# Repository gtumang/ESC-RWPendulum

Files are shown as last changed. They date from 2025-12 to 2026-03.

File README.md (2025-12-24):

# ESC-RWPendulum

Este repositório contém o firmware, modelos de simulação e ferramentas de visualização para um sistema de controle de **Pêndulo com Roda de Reação** (Pêndulo Invertido). O projeto foi projetado para estabilizar o pêndulo usando uma roda de reação acionada por um motor DC, controlado por um microcontrolador ESP32.

## Estrutura do Projeto

O repositório está organizado em quatro diretórios principais:

* **`Firmware/`**: Código C++ embarcado para o ESP32, construído usando PlatformIO. Gerencia a leitura de sensores, a execução da malha de controle e a comunicação serial.
* **`Matlab/`**: Scripts MATLAB e modelos Simulink para definição de parâmetros físicos, modelagem matemática e cálculo de ganho de controle (LQR).
* **`Visualization/`**: Scripts Python para telemetria em tempo real, registro de dados e plotagem via Serial.
* **`PCB/`**: Arquivos de projeto da placa de circuito impresso (Hardware), incluindo esquemáticos, layout e arquivos de fabricação.

---

## 1. Firmware (ESP32)

O firmware está localizado no diretório `Firmware` e está configurado como um projeto **PlatformIO**.

### Configuração de Hardware
* **Microcontrolador**: ESP32 (Placa: `fm-devkit`)
* **Atuador**: Motor DC com driver PWM (controlado pelos pinos 25/26).
* **Sensores**: Dois Encoders de Quadratura (Ângulo do Pêndulo e Velocidade da Roda).

**Pinagem (`main.cpp`):**
| Componente | Pino A | Pino B | Notas |
| :--- | :--- | :--- | :--- |
| **Encoder da Roda** | GPIO 17 | GPIO 16 | Mede velocidade/posição da roda de reação |
| **Encoder do Pêndulo** | GPIO 19 | GPIO 18 | Mede o ângulo de inclinação do pêndulo |
| **Driver do Motor** | GPIO 25 | GPIO 26 | Saída PWM (LEDC) |
| **Botão Iniciar/Parar**| GPIO 4 | - | Alterna a malha de controle (ISR) |

### Malha de Controle
* **Algoritmo**: Controle em Espaço de Estados (LQR).
* **Frequência**: 50 Hz (`Ts = 0.02s`).
* **Estados**:
    1.  $x_1$: Ângulo do Pêndulo (rad)
    2.  $x_2$: Ângulo da Roda (rad)
    3.  $x_3$: Velocidade do Pêndulo (rad/s)
    4.  $x_4$: Velocidade da Roda (rad/s)
* **Comunicação**: Envia dados de estado e esforço de controle via Serial (Formato binário).

---
## 2. MATLAB & Simulação

O diretório `Matlab` contém a fundação matemática do projeto.

* **`Scripts/SalvaParams.m`**: Define as constantes físicas do sistema (massas, comprimentos, inércia, constantes do motor) e as salva em `Parametros/parametros_planta.mat`.
    * *Parâmetros incluem:* $M_h$ (Massa da haste), $M_r$ (Massa do rotor), $L$ (Comprimento), $J_h$ (Inércia), etc.
* **`PenduloRotativoSim.slx`**: Modelo Simulink para simular a dinâmica do sistema e a resposta do controlador.
* **`Funcoes/`**: Contém funções geradas automaticamente (`function_G_Rot`, `function_M_Rot`, etc.) para a simulação não linear do sistema.
* **`Parametros/`**: Armazena arquivos `.mat` com a matriz de ganho de controle `K` calculada.

**Como usar:**
1.  Edite os parâmetros físicos em `SalvaParams.m` e execute-o.
2.  Execute o script de análise principal (ex: `main.mlx`) para calcular a matriz de ganho LQR $K$.
3.  Atualize a struct `K` em `Firmware/src/main.cpp` com os valores calculados.

---

## 3. Visualização (Python)

O diretório `Visualization` fornece ferramentas para visualizar dados do sistema em tempo real.

### Requisitos
* Python 3.x
* Bibliotecas: `pyserial`, `matplotlib`

### Scripts
* **`ler_pendulo.py`**: Um utilitário simples para ler dados brutos da porta serial e imprimir os valores decodificados em ponto flutuante no console.
* **`plot_pendulo.py`**: Uma ferramenta de plotagem em tempo real.
    * **Uso**: `python plot_pendulo.py --port COM3`
    * **Recursos**:
        * Plota múltiplas variáveis dinamicamente.
        * Suporta um modo de simulação para testar a interface sem hardware: `python plot_pendulo.py --sim`.
        * Visualiza Ângulo, Velocidade e Esforço de Controle ($u$).

---

## 4. Hardware e PCB (KiCad)

O diretório **`PCB`** contém todo o projeto eletrônico necessário para fabricar a placa de controle customizada do pêndulo, desenvolvido no software **KiCad**.

### Estrutura dos Arquivos
* **`RWPendulum/`**: Contém os arquivos fonte do projeto KiCad, incluindo o esquemático (`.kicad_sch`) e o layout da PCB (`.kicad_pcb`). O design integra o módulo ESP32 DevKit V1 e o driver de motor.
* **`OutputFiles/`**: Arquivos gerados para fabricação da placa:
    * **`Gerber/`**: Arquivos Gerber para as camadas de cobre, máscara de solda e corte.
    * **`Drill/`**: Arquivos de furação (PTH e NPTH).
* **`3D/`**: Modelos 3D (.step) da placa completa e componentes específicos (ex: Driver MD36A) para visualização mecânica e validação de encaixe.

---

## Licença
*Nenhuma licença especificada nos arquivos do repositório*.

## Autor
**Gabriel Brunoro Motta Tumang**

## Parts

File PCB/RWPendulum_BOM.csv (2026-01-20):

Id | Designator | Footprint | Quantity | Designation | Supplier and ref
1 | SW2 | SW_PUSH_6mm_H4.3mm | 1 | SW_Push
2 | C1,C2,C4,C3 | C_Disc_D5.0mm_W2.5mm_P5.00mm | 4 | 100nF
3 | IC1 | TO255P460X1020X2008-3P | 1 | L7805CV
4 | J1,J4 | TerminalBlock_MaiXu_MX126-5.0-02P_1x02_P5.00mm | 2 | Screw_Terminal_01x02
5 | C5 | CP_Radial_D8.0mm_P3.50mm | 1 | 470uF
6 | F1 | Fuseholder_Cylinder-5x20mm_Schurter_0031_8201_Horizontal_Open | 1 | Fuse
7 | U2 | ESP32-C3-DevKitM-1 | 1 | ESP32-DEVKIT-V1
8 | D1 | LED_D3.0mm | 1 | LED
9 | J3 | Molex_KK-396_A-41792-0004_1x04_P3.96mm_Horizontal | 1 | Conn_01x04_Pin
10 | J2 | Molex_KK-396_A-41792-0006_1x06_P3.96mm_Horizontal | 1 | Conn_01x06_Pin
11 | A1 | MD36A Motor Driver Header | 1 | ~
12 | R2 | R_Axial_DIN0207_L6.3mm_D2.5mm_P10.16mm_Horizontal | 1 | 600
13 | SW1 | TerminalBlock_MaiXu_MX126-5.0-02P_1x02_P5.00mm | 1 | SW_SPST

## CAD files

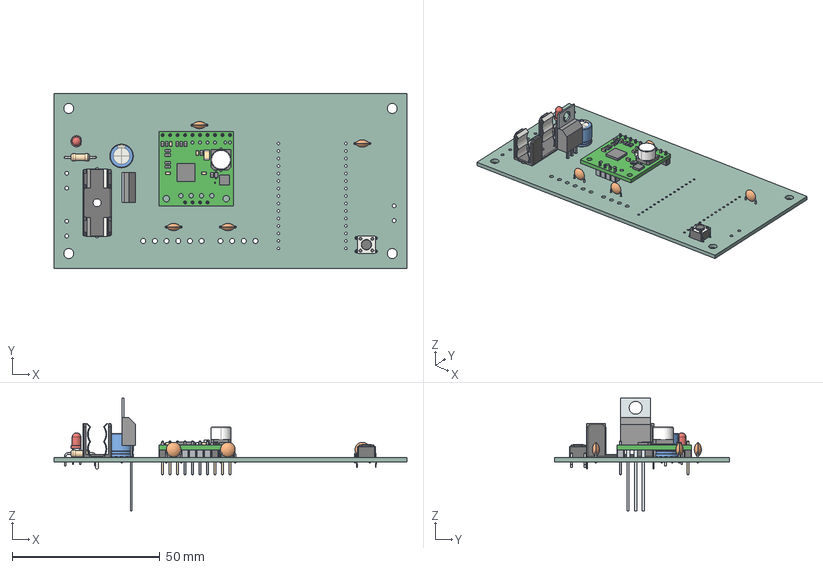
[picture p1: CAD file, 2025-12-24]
PCB/3D/RWPendulum.step
119.6 x 59.2 x 38.3 mm
SW_PUSH_6mm_H4.3mm
C_Disc_D5.0mm_W2.5mm_P5.00mm x 4
Tab
PinsArray
CP_Radial_D8.0mm_P3.50mm
Fuseholder_Cylinder-5x20mm_Schurter_0031_8201_Horizontal_Open
LED_D3.0mm
Barra10Pinos
tb9051ftg_single_brushed_dc_motor_driver_carrier
Slice.1
R_Axial_DIN0207_L6.3mm_D2.5mm_P10.16mm_Horizontal
RWPendulum_PCB

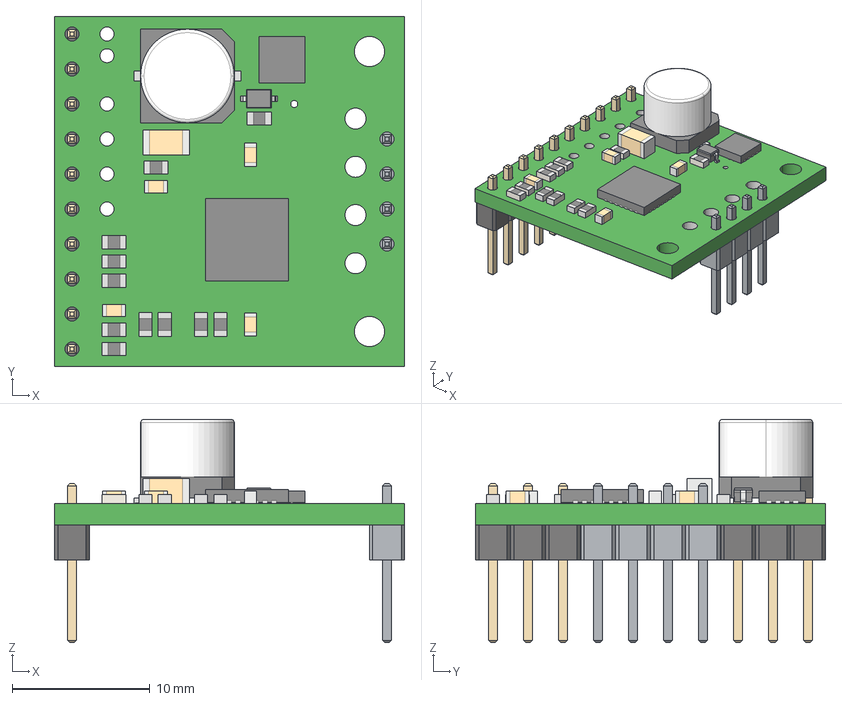
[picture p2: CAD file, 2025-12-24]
PCB/3D/MD36A_MotorDriver_Header.step
25.4 x 25.4 x 16.2 mm
Barra10Pinos
tb9051ftg_single_brushed_dc_motor_driver_carrier
Slice.1

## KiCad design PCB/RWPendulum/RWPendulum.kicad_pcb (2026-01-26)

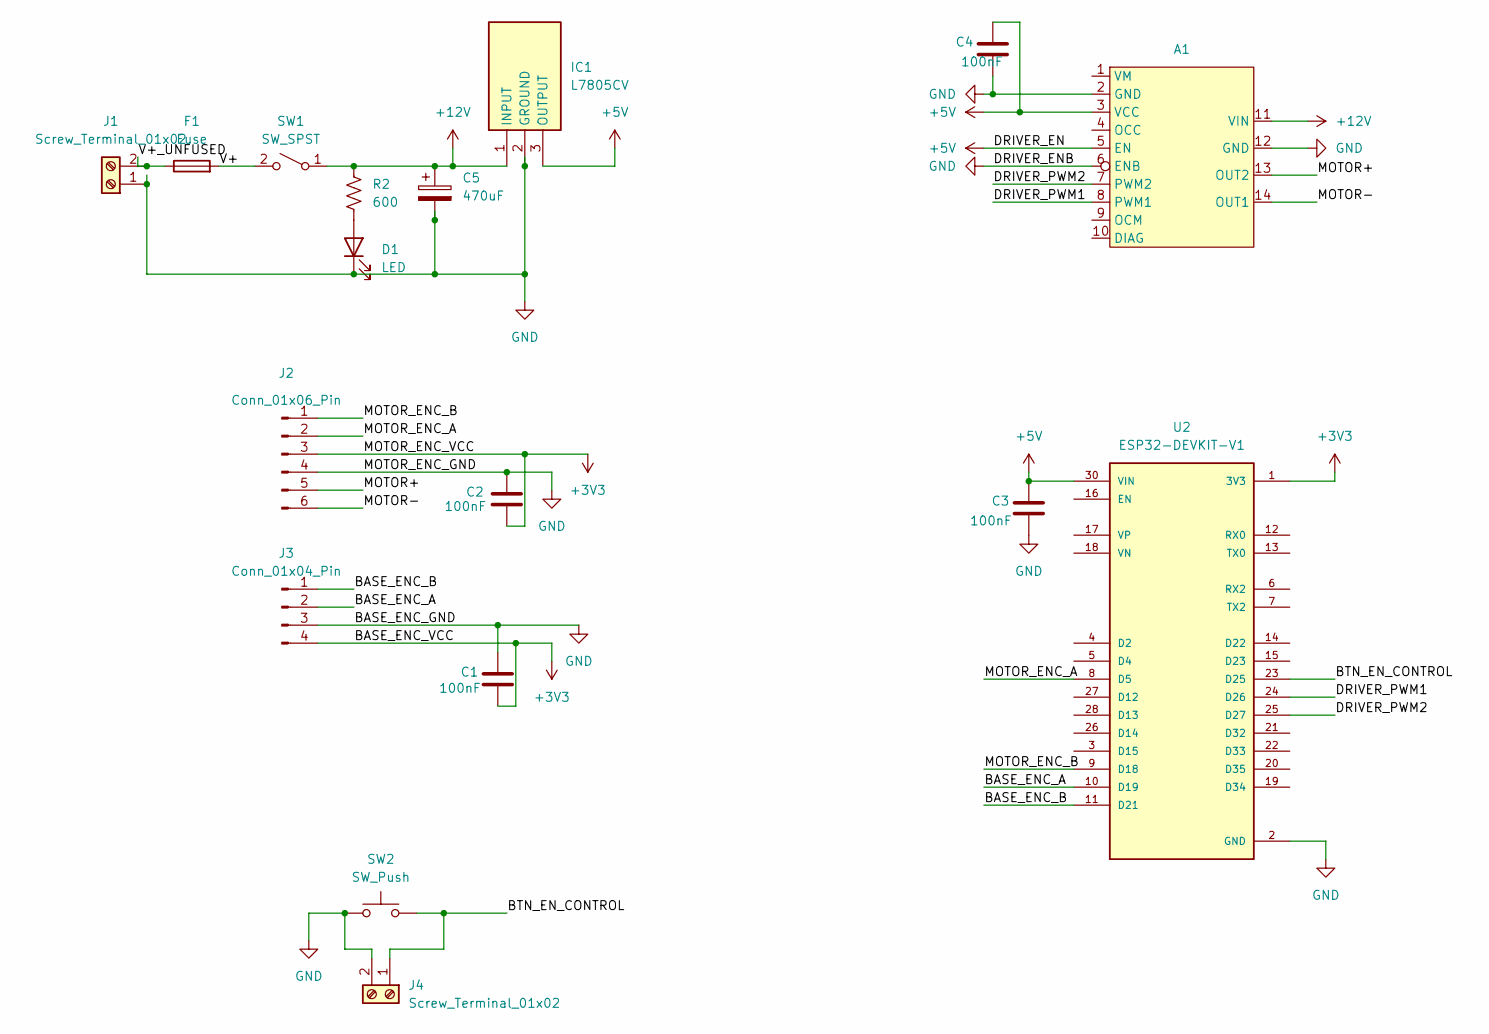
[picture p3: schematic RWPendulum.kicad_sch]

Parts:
A1: MD36A Motor Driver Header
C1, C2, C3, C4: 100nF; C_Disc_D5.0mm_W2.5mm_P5.00mm
C5: 470uF; CP_Radial_D8.0mm_P3.50mm
D1: LED; LED_D3.0mm
F1: Fuse; Fuseholder_Cylinder-5x20mm_Schurter_0031_8201_Horizontal_Op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
IC1: L7805CV; TO255P460X1020X2008-3P; Manufacturer_Part_Number L7805CV; Mouser Part Number 511-L7805CV
J1, J4: Screw_Terminal_01x02; TerminalBlock_MaiXu_MX126-5.0-02P_1x02_P5.00mm
J2: Conn_01x06_Pin; Molex_KK-396_A-41792-0006_1x06_P3.96mm_Horizontal
J3: Conn_01x04_Pin; Molex_KK-396_A-41792-0004_1x04_P3.96mm_Horizontal
R2: 600; R_Axial_DIN0207_L6.3mm_D2.5mm_P10.16mm_Horizontal
SW1: SW_SPST; TerminalBlock_MaiXu_MX126-5.0-02P_1x02_P5.00mm
SW2: SW_Push; SW_PUSH_6mm_H4.3mm
U2: ESP32-DEVKIT-V1; ESP32-C3-DevKitM-1; PARTREV N/A

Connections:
+3V3: C1.2, C2.2, J2.3, J3.4, U2.1 (3V3)
+5V: A1.3 (VCC), A1.5 (EN), C3.1, C4.1, IC1.3 (OUTPUT), U2.30 (VIN)
+12V: A1.11 (VIN), C5.1, IC1.1 (INPUT), R2.2, SW1.1 (A)
/BASE_ENC_A: J3.2, U2.10 (D19)
/BASE_ENC_B: J3.1, U2.11 (D21)
/BTN_EN_CONTROL: J4.1, SW2.2, U2.23 (D25)
/DRIVER_PWM1: A1.8 (PWM1), U2.24 (D26)
/DRIVER_PWM2: A1.7 (PWM2), U2.25 (D27)
/MOTOR+: A1.13 (OUT2), J2.5
/MOTOR-: A1.14 (OUT1), J2.6
/MOTOR_ENC_A: J2.2, U2.8 (D5)
/MOTOR_ENC_B: J2.1, U2.9 (D18)
/V+: F1.2, SW1.2 (B)
/V+_UNFUSED: F1.1, J1.2
GND: A1.2 (GND), A1.6 (ENB), A1.12 (GND), C1.1, C2.1, C3.2, C4.2, C5.2, D1.1 (K), IC1.2 (GROUND), J1.1, J2.4, J3.3, J4.2, SW2.1, U2.2 (GND), U2.29 (GND)
unnamed: D1.2 (A), R2.1

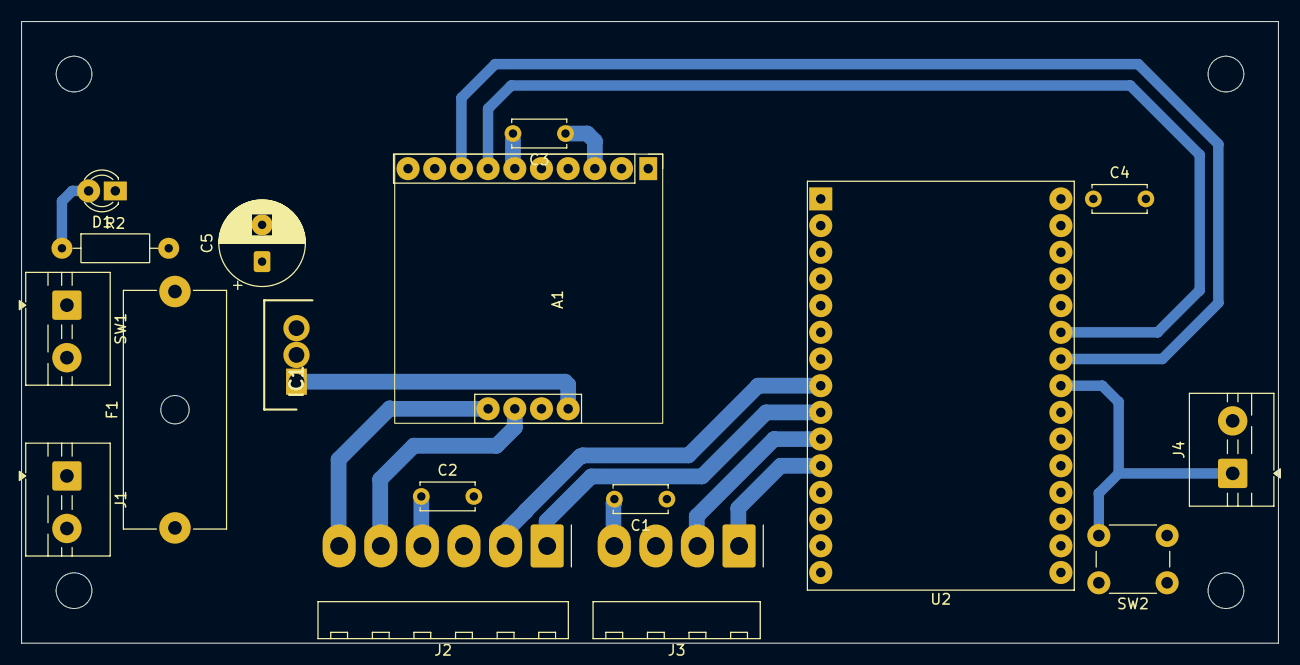
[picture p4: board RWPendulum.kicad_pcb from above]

Board: 2 copper layers, 119.6 x 59.2 mm, 17 parts (0 on the bottom side), 16 nets.

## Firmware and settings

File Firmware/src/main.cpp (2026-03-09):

#include <Arduino.h>
#include <ESP32Encoder.h>
#include "defines.h"



// Definições para adquirir informações
// Condicoes iniciais
#if ACQSIGNAL==true
#define acq_time 10.0 //s
#define acq_arr_size acq_time/Ts
const int arr_size = (int) acq_arr_size;
estados_t state_arr[arr_size];
bool acq_done = false;
int i = 0;
#endif

// Variaveis Globais Auxiliares p/ Lógica
estados_t estados{
  .x1 = 0.0f,
  .x2 = 0.0f,
  .x3 = 0.0f,
  .x4 = 0.0f
};
estados_t estados_ant{
  .x1 = 0.0f,
  .x2 = 0.0f,
  .x3 = 0.0f,
  .x4 = 0.0f
};
estados_t estados_ant_unf{
  .x1 = 0.0f,
  .x2 = 0.0f,
  .x3 = 0.0f,
  .x4 = 0.0f
};
// Ganho controlador
static const estados_t K{
  .x1 = LQR_K1,
  .x2 = LQR_K2,
  .x3 = LQR_K3,
  .x4 = LQR_K4
};
volatile bool aux = false;
bool enable_cont = false;
double u_hist=0;


//// Objetos globais
// Encoder
ESP32Encoder enc_roda;
ESP32Encoder enc_pend;
// Timer
hw_timer_t *timer = NULL;
// RTOS
TaskHandle_t handleControle;
TaskHandle_t handleComunicacao;
SemaphoreHandle_t handleMutex = NULL;

// Configuração PWM
const int pwmChannelA = 0;
const int pwmChannelB = 1;
const int pwmResolution = 8;
const int pwmFrequency = 10000;

void IRAM_ATTR onTimer() {
  aux = true;
}

// Declarações de Funções
void drive(float u);
void montaMensagem(u_char* msg, estados_t estados);
double ajusta_angulo(double angulo);
double controle(estados_t x, estados_t k);
static const double backwards_uf(double q, double q_ant, double ts);
static const double backwards_filtered(double q, double q_ant, double qp_ant, double qp_ant_uf, double a, double b, double ts);
static const double sign(double x);

// Definição das Funções-Tarefas
void taskControle(void* pvParameters);
void taskComunicacao(void* pvParameters);

// ISRs
void enable_cont_ISR(){
  enable_cont = !enable_cont;
}

void setup() {
  Serial.begin(9600);

  // ConfiguraÇão botoes
  pinMode(BOTAO_CONT, INPUT_PULLUP);
  // pinMode(BOTAO_SU, INPUT_PULLDOWN);
  attachInterrupt(digitalPinToInterrupt(BOTAO_CONT), enable_cont_ISR, RISING);

  // Configuração dos encoders
  pinMode(ENC_RODA_A, INPUT);
  pinMode(ENC_RODA_B, INPUT);
  ESP32Encoder::useInternalWeakPullResistors = puType::up;
  enc_roda.attachFullQuad(ENC_RODA_A, ENC_RODA_B);
  enc_pend.attachFullQuad(ENC_PEND_A, ENC_PEND_B);
  enc_roda.clearCount();
  enc_pend.clearCount();

  // Configuração do motor
  ledcSetup(pwmChannelA, pwmFrequency, pwmResolution);
  ledcSetup(pwmChannelB, pwmFrequency, pwmResolution);
  ledcAttachPin(IN_A, pwmChannelA);
  ledcAttachPin(IN_B, pwmChannelB);

  // LED onboard
  pinMode(ONBOARD_LED, OUTPUT);
  digitalWrite(ONBOARD_LED, HIGH);

  // Configuração do timer
  timer = timerBegin(0, 80, true); // Divisor de 80 (1MHz)
  timerAttachInterrupt(timer, &onTimer, true);
  timerAlarmWrite(timer, Ts * 1000000, true);
  timerAlarmEnable(timer);
  
  // Pega ângulo inicial
  Serial.println("");
  Serial.println("-----------------------");
  Serial.println("-------Iniciando!------");
  Serial.println("-----------------------");

  // Configura mutex
  handleMutex = xSemaphoreCreateMutex();

  delay(1000); // Espera inicial de 5 segundos

  // Configura taks
  xTaskCreatePinnedToCore(
    taskControle,
    "TaskControle",
    1000,
    NULL,
    1,
    &handleControle,
    1
  );

  xTaskCreatePinnedToCore(
    taskComunicacao,
    "TaskComunicacao",
    1000,
    NULL,
    1,
    &handleComunicacao,
    0
  );
}

void taskControle(void* pvParameteres){
  for(;;){
    if(aux) {
      aux = false;
      if(xSemaphoreTake(handleMutex, portMAX_DELAY)) {


        estados.x1 = enc_pend.getCount() * en2rad_pend;
        estados.x2 = enc_roda.getCount() * en2rad_roda;
        estados.x3 = backwards_uf(estados.x1, estados_ant.x1, Ts);
        estados.x4 = backwards_uf(estados.x2, estados_ant.x2, Ts);

        estados_ant = estados;

        estados.x1 = ajusta_angulo(estados.x1);

        double u = controle(estados, K);

        if(!enable_cont) u=0.0f;
        drive(u);

        u_hist = u;
        xSemaphoreGive(handleMutex);
      }
    }
  }
}

void taskComunicacao(void* pvParameters){
  estados_t X_com = {
    .x1 = 0.0,
    .x2 = 0.0,
    .x3 = 0.0,
    .x4 = 0.0,
  };
  u_char* msg = (u_char*) malloc(TAMANHO_FRAME);
  for(;;){
    
    if(xSemaphoreTake(handleMutex, 200 * portTICK_PERIOD_MS)){
      X_com = estados;
      xSemaphoreGive(handleMutex);
      montaMensagem(msg, X_com);
      Serial.write(msg, TAMANHO_FRAME);
    }
    delay(100);
  }
  free(msg);
};

void loop() {}

void drive(float u) {
  int direction = 0;
  if (u > 0) direction = 1;
  if (u < 0) direction = 2;

  u = fabs(u);
  u = constrain(u, 0.0f, 1.0f);
  //ledcWrite(pwmChannel, (uint32_t)(u * 255));

  switch(direction) {
    case 0:
      ledcWrite(pwmChannelA, (uint32_t)(0 * 255));
      ledcWrite(pwmChannelB, (uint32_t)(0 * 255));
      break;
    case 1:
    
      ledcWrite(pwmChannelA, (uint32_t)(u * 255));
      ledcWrite(pwmChannelB, (uint32_t)(0 * 255));
      break;
    case 2:
      ledcWrite(pwmChannelA, (uint32_t)(0 * 255));
      ledcWrite(pwmChannelB, (uint32_t)(u * 255));
      break;
  }
}

static const double backwards_uf(double q, double q_ant, double ts){
  return 1.0f/Ts*(q - q_ant);
}
static const double backwards_filtered(double q, double q_ant, double qp_ant, double qp_ant_uf, double a, double b, double ts){
  return a*(backwards_uf(q, q_ant, ts) + qp_ant_uf) - b*qp_ant;
}

static const double sign(double x){
  return x!=0 ? x/abs(x) : 0;
}

double ajusta_angulo(double angulo){
  if(abs(angulo) > 2*pi){
    angulo = fmod(angulo, 2*pi);
  }
  double angulo_pra_cima = angulo - sign(angulo)*pi;
  return angulo_pra_cima;
}

double controle(estados_t x, estados_t k){
  return -k.x1 * x.x1 -k.x2 * x.x2 -k.x3 * x.x3 -k.x4 * x.x4;
}

void montaMensagem(u_char* msg, estados_t estados){
  msg[0] = 0xFF;
  memcpy(msg + 1 + 0*DOUBLE_SIZE, &estados.x1, DOUBLE_SIZE);
  memcpy(msg + 1 + 1*DOUBLE_SIZE, &estados.x2, DOUBLE_SIZE);
  memcpy(msg + 1 + 2*DOUBLE_SIZE, &estados.x3, DOUBLE_SIZE);
  memcpy(msg + 1 + 3*DOUBLE_SIZE, &estados.x4, DOUBLE_SIZE);
  memcpy(msg + 1 + 4*DOUBLE_SIZE, &u_hist, DOUBLE_SIZE);
  msg[1 + TAMANHO_PAYLOAD] = 0x00;
}

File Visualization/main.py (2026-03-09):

#!/usr/bin/env python3
"""
plot_multi_dynamic.py

Leitura de frames seriais: 0xFF (5 doubles little-endian) 0x00
Cria múltiplas figuras matplotlib dinamicamente a partir do mesmo stream.
Cada figura pode plotar qualquer combinação das variáveis d1..d5.
"""

import argparse
import struct
import threading
import time
from collections import deque
from typing import List, Tuple

import matplotlib.pyplot as plt
import matplotlib.animation as animation

# --- opcional: pyserial para leitura real ---
try:
    import serial
except Exception:
    serial = None

# --- Configurações padrão ---
SERIAL_PORT = "COM4"    # ex: "COM3" no Windows
BAUDRATE = 9600
TIMEOUT = 0.5

START_BYTE = 0xFF
END_BYTE = 0x00
DOUBLES_COUNT = 5
DOUBLE_SIZE = 8
PAYLOAD_SIZE = DOUBLES_COUNT * DOUBLE_SIZE  # 40 bytes

BUFFER_SECONDS = 30
UPDATE_INTERVAL_MS = 100
MAX_POINTS = int(BUFFER_SECONDS * 1000 / UPDATE_INTERVAL_MS)

# --- leitor serial em background (preenche deque) ---
def read_frame_from_serial(ser) -> Tuple[float, ...] or None:
    """Lê um frame e retorna tuple (d1..d5) ou None se timeout/erro."""
    # procurar start
    while True:
        b = ser.read(1)
        if not b:
            return None
        if b[0] == START_BYTE:
            break

    payload = bytearray()
    remaining = PAYLOAD_SIZE
    while remaining > 0:
        chunk = ser.read(remaining)
        if not chunk:
            return None
        payload.extend(chunk)
        remaining = PAYLOAD_SIZE - len(payload)

    end = ser.read(1)
    if not end or end[0] != END_BYTE:
        return None

    try:
        return struct.unpack("<5d", payload)
    except struct.error:
        return None


def serial_reader_thread(data_deque: deque, lock: threading.Lock, stop_event: threading.Event,
                         port: str, baud: int, timeout: float, simulate: bool):
    """
    Popula data_deque com tuplas (timestamp, d1, d2, d3, d4, d5).
    Usar lock ao acessar data_deque para thread-safety.
    """
    if simulate:
        print("SIMULANDO dados (modo --sim).")
        import math
        t0 = time.time()
        while not stop_event.is_set():
            t = time.time()
            d1 = 2.0 * math.sin(2 * math.pi * 0.2 * (t - t0)) + 0.1 * math.sin(t * 3.3)
            d2 = 0.5 * math.sin(2 * math.pi * 0.5 * (t - t0))
            d3 = 0.2 * math.cos(2 * math.pi * 0.8 * (t - t0))
            d4 = 0.0
            d5 = 1.5 * math.cos(2 * math.pi * 0.1 * (t - t0)) + 0.05 * math.sin(t * 1.7)
            with lock:
                data_deque.append((t, d1, d2, d3, d4, d5))
                while len(data_deque) > MAX_POINTS:
                    data_deque.popleft()
            time.sleep(UPDATE_INTERVAL_MS / 1000.0)
        return

    # leitura real
    if serial is None:
        print("pyserial não disponível. Instale 'pyserial' ou use --sim.")
        return

    try:
        ser = serial.Serial(port, baud, timeout=timeout)
    except Exception as e:
        print("Erro abrindo serial:", e)
        return

    print(f"Conectado em {port} @ {baud}")
    try:
        while not stop_event.is_set():
            frame = read_frame_from_serial(ser)
            if frame is None:
                continue
            t = time.time()
            with lock:
                data_deque.append((t, *frame))
                while len(data_deque) > MAX_POINTS:
                    data_deque.popleft()
    finally:
        ser.close()


# --- função reutilizável que cria uma figura/animation ---
def create_figure(
    data_deque: deque,
    lock: threading.Lock,
    var_indices: List[int],
    *,
    separate_y: bool = False,
    buffer_seconds: float = BUFFER_SECONDS,
    update_interval_ms: int = UPDATE_INTERVAL_MS,
    fig_title: str = None,
) -> Tuple[plt.Figure, animation.FuncAnimation]:
    """
    Cria uma figura que plota as variáveis em var_indices (1-based: 1..5).
    - var_indices: lista de índices (ex: [1,5] para d1 e d5).
    - separate_y: se True cria subplots empilhados, um por variável (eixos Y independentes),
                  se False plota todas no mesmo eixo (mesmo Y).
    Retorna (fig, anim) — mantenha references no caller para evitar GC.
    """
    # valida índices
    for idx in var_indices:
        if idx < 1 or idx > DOUBLES_COUNT:
            raise ValueError("var_indices deve conter valores entre 1 e 5 (inclusive)")

    n_vars = len(var_indices)
    fig = None
    axes = []
    lines = []
    last_texts = []

    if separate_y:
        fig, axes = plt.subplots(n_vars, 1, sharex=True, figsize=(8, 3 * n_vars))
        # quando n_vars == 1, axes pode não ser uma lista
        if n_vars == 1:
            axes = [axes]
        for i, ax in enumerate(axes):
            ax.grid(True)
            ax.set_ylabel(f"d{var_indices[i]}")
            ln, = ax.plot([], [], lw=1, label=f"d{var_indices[i]}")
            ax.legend(loc="upper right")
            lines.append(ln)
            last_texts.append(ax.text(0.02, 0.9, "", transform=ax.transAxes, va="top"))
        axes[-1].set_xlabel("Tempo (s, relativo)")
        if fig_title:
            fig.suptitle(fig_title)
    else:
        fig, ax = plt.subplots(figsize=(10, 4))
        if fig_title:
            fig.suptitle(fig_title)
        ax.set_xlabel("Tempo (s, relativo)")
        ax.set_ylabel("Valor")
        ax.grid(True)
        for idx in var_indices:
            ln, = ax.plot([], [], lw=1, label=f"d{idx}")
            lines.append(ln)
        ax.legend(loc="upper right")
        axes = [ax]
        last_texts = [ax.text(0.02, 0.95, "", transform=ax.transAxes, va="top")]

    # init function
    def init():
        for ax in axes:
            ax.set_xlim(0, buffer_seconds)
            ax.set_ylim(-1.0, 1.0)
        for ln in lines:
            ln.set_data([], [])
        for t in last_texts:
            t.set_text("")
        return (*lines, *last_texts)

    # update function
    def update(_):
        with lock:
            if not data_deque:
                return (*lines, *last_texts)
            # fazer cópia leve dos dados para processamento fora do lock (lista de tuplas)
            data_copy = list(data_deque)

        times = [t for (t, *_) in data_copy]
        t0 = times[0]
        x_rel = [tt - t0 for tt in times]
        x_max = x_rel[-1]
        x_min = max(0.0, x_max - buffer_seconds)

        # extrair vetores para cada variável solicitada
        ys = []
        for var_idx in var_indices:
            # var_idx é 1-based e os dados são (t, d1, d2, d3, d4, d5)
            pos = var_idx  # because tuple index 1 corresponds to d1
            ys.append([row[pos] for row in data_copy])  # row[pos] é d{var_idx}
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

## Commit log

2025-12-04 Commit inicial
    Adicionando arquivos de matlab contendo:
    - Modelagem do pendulo e sintonizacao do LQR
    - Simulink contendo simulação do pendulo
    - Arquivos de parâmetros
    - Funções de apoio para extração de parâmetros a partir de dados reais e geração do arquivo de parâmetros da planta
    - Dados reais da planta
2025-12-04 Criando diretório para matlab
2025-12-04 Adicionado arquivos fonte para firmware e para visualização em tempo real para PC
2025-12-24 Adicionado projeto da PCB e outras refatorações de diretórios e nomes de arquivos
    [MD36A_MotorDriver_Header.step, RWPendulum.kicad_pcb, RWPendulum.kicad_sch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]
2025-12-24 Atualziando readme para falar sobre o hardware
2026-01-20 Atualizado design da PCB e arquivos gerber + drill
    [RWPendulum.kicad_pcb, RWPendulum_BOM.csv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]
2026-01-26 Atualizando pinos de GPIO para utilizar a planta com PCB
2026-01-26 PCB: Rev. 1 - Gabriel Tumang - 22/01/2026
    Mudando pino do botão EN_CONTROL para 27 no lugar do 34 para utilizar função de pullup interno da ESP32,
    por consequência, os pinos de PWM p/ o driver foram modvidos para facilitar o roteamento.
    Também foram alterados tamanhos dos furos e pads de alguns componentes para tentar minimizar problemas de fabricação.
    [RWPendulum.kicad_pcb, RWPendulum.kicad_sch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]
2026-03-09 Implementação do ESC e adicionado script para enviar dados de simulação para visualização
2026-03-09 - Criando projeto UV para visualização serial. - Separando definições para arquivo defines.h
